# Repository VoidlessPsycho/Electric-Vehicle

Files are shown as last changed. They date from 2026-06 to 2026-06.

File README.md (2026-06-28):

# Voidless's Electric Vehicle

This project is an Electric Vehicle for the Science Olympiad Electric Vehicle event for the 2026-27 season. It uses N20 Motors, TB6612FNG Motor Driver, and ESP32 for movement.

**Demo Video:** https://youtu.be/8lS0Rzt4JzQ

Angle View Front
Angle View Back

[Journal](JOURNAL.md)

## How to Use
1. Turn on power by pressing button from battery pack.
2. Upload code from computer using USB-C and Arduino IDE.
3. Align toothpick and vehicle with start point on track, facing straight forward.
4. Use a pencil to press button in center of vehicle.

## How it Works
1. Pins are assigned to variables.
2. There is a configurable segments object to determine how far to go for each segment of the path. 
3. When the button is pressed, the motion part of the script activates. 
4. The vehicle uses encoder feedback and compares it to the calculated position of each motor to determine which segment the vehicle currently needs to be on, and uses PID loops and if statements to control the vehicle speed and direction.
5. The vehicle stops once it is detected that the vehicle has passed through all the segments. 

## Tech Stack
- Arduino IDE
- C++ (Programming)
- Onshape (CAD)
- Freeform/Excalidraw/Notebook (Brainstorming)
- Desmos Graphing Calculator (Path Planning)
- VS Code (Repository Management)
- Markdown (Journaling/Documentation)

AI Declaration: AI was used in programming the firmware for this device. 

## Images
CAD: \
Front
Side

[Wiring](https://app.cirkitdesigner.com/project/edc74d5a-a196-4ad5-98cb-bc518ee554fb): \
Circuit

Bill of Materials:
- 1 x Push Button
- 1 x 6xAA Battery Holder
- 6 x AA Batteries
- 1 x Ball Castor
- 2 x Banebots T40 1.625x5/8 in Wheels + Hubs
- 2 x 12V 1:30 Gearbox Polulu N20 Motors with Encoders
- 1 x ESP32 DevKit V1
- 1 x TB6612FNG Motor Driver
- 1 x 3D Printed Frame
- 1 x 3D Printed Motor Holder
- Dupont Wires (Female-Female)

## Motivation
I selected this event for Science Olympiad as I was interested in electronics. This event requires programming a microcontroller with C++ and learning motor control structures, like using PID control loops, trapezoidal motion profiles, and H-Bridge motor drivers. This project is meant to be a competitive device for the Electric Vehicle event, and I won 4th place with it at my Regional Tournament.

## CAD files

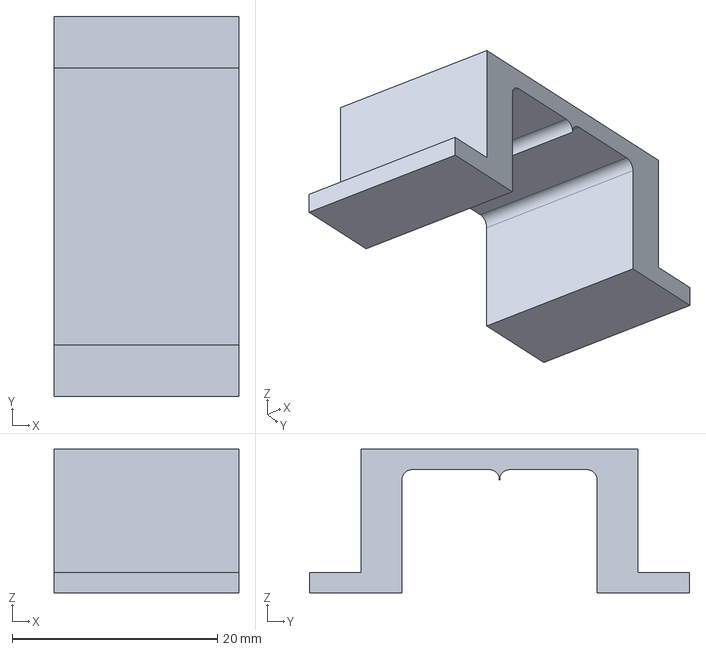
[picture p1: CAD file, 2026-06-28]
CAD/Motor Holder.step
18.0 x 37.0 x 14.0 mm

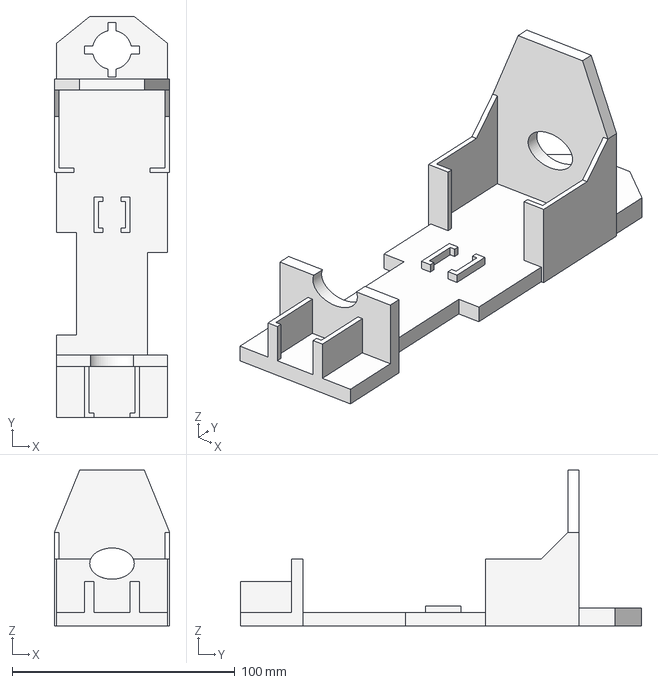
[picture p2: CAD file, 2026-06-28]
CAD/Frame.step
51.8 x 180.0 x 70.0 mm

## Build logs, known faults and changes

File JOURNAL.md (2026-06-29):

# Journal

**Total Number of Entries: 43** \
**Total Time Spent: 93.5 hours**

<hr>

### September 10, 2025: Analyzing Rules
I read through the guidelines for the Electric Vehicle event to figure out exactly what I had to do. The rules also included constraints on what I cannot do, such as limiting power to a maximum of 8 x AA Batteries for max of 12 V. \
The challenge requires the vehicle to go from the start point to the end point in a set amount of time. For bonus points, it can go through a gap made by cans to the left. This track is illustrated in the image below: \


**Time spent this session: 1 hour**
<hr>

### September 17: Finding Parts on Amazon
I knew I needed to make a robot car, with two motors, a microcontroller, and a motor driver. I decided to look for these components on Amazon. 

**Motors:** Because the Electric Vehicle had to be as thin as possible to get the most can bonus (cans closer together = more bonus points), I needed small motors so my chassis isn't too big. I found a type of motor called an N20 motor, which had a very small size. I found a lot of different options on both the Polulu (robotics parts company) website and Amazon. 
>   

**Microcontroller:** As I don't know too much about electronics yet, I wanted to go with a simple microcontroller that is beginner-friendly. I looked at the popular Arduino Uno R3, and its cheaper alternative, the Elegoo Uno R3. 
>  

**Motor Driver:** To control the motors using Pulse Width Modulation (PWM), a motor driver is necessary. I looked at the TB6612FNG module, which is an H-Bridge motor driver.
> 

Still need to decide which motors, microcontrollers, and motor drivers to buy specifically for my use case.

**Time spent this session: 2 hours**
<hr>

### October 8: Buying Basic Electronics
One thing I didn't discuss in the previous journal is what wheels I was gonna use. This is because I was thinking of using CDs as I have in other vehicle projects, albeit those were not electric. My "Scrambler" project I made previously looks similar to the below picture below, with CDs for wheels. 

 \
However, the CDs broke extremely easily, especially after using superglue to attach them to the axle. After remembering this, I decided to **NOT** use CDs for this project going forward.

The plan is to first buy basic parts like an Arduino, motors, etc., then figure out how to make the vehicle curve/follow and angular path and program it. 

**Steering Method:** First, I wanted to try the caliper steering method, and then the differential steering method if I am unable to implement caliper steering. Caliper steering requires more CADding, and differential steering requires more programming. 

**Parts Choices:** Below is an Amazon cart screenshot of different items I debated on purchasing: (Censored PII)

- **Motor**: I went back and reviewed my motor choices. N20 Motors can be used for both differential steering and caliper steering. I looked for some of these on Amazon, and I [found one](https://www.amazon.com/dp/B0F8NLB4CD/), but it didn't have any reviews, so I ended up not purchasing it. 
- **Microcontroller**: I chose to buy the [Elegoo Uno R3](https://www.amazon.com/ELEGOO-Starter-Tutorial-Compatible-Official/dp/B01DGD2GAO/)  because of it being cheaper than the Arduino Uno R3 for the same features, and also got a starter kit so that I could have other electronics to experiment with.
- **Motor Driver:** The [TB6612FNG](https://www.amazon.com/gp/product/B08J3S6G2N/) was more efficient than the L298n Motor Driver, but because I didnt have a [soldering iron](https://www.amazon.com/Soldering-Digital-Welding-Portable-Electric/dp/B08R3515SF/), I decided to go with the L298n instead.

I want to use a 3D-printed frame, a breadboard, and tape if necessary to construct my EV. 

Items I bought today:


**Time spent this session: 2.5 hours**
<hr>

### October 14: Experimenting with the Basic Kit
I got my Elegoo Starter Kit and started experimenting with it. If I need it, I'll get a Raspberry Pi Pico later. 

The battery pack had 12V and GND wires, but the ends were too big to fit into the breadboard power rails easily. This made it so the LED didn't light up.



I decided to use the power pins from the Elegoo Uno, and using a resistor made the LED light up properly and not burn out.



This is my first successful circuit!

**Time spent this session: 1.5 hours**
<hr>

### October 18: Motor Movement
I got the motor driver and motor, so I could finally start some moving parts. The L298n had screw terminals to attach the motors and other wires to. 

I made an Arduino program to make sure my motors worked. It spins the motor forward, spins it the other way, then stops. I also added interrupts to the encoders so I could track motor position on the serial encoder.

Motor Setup

Demo of Motor moving: https://youtu.be/Mmbqhapk2sQ

I also got a caliper for caliper steering and measurements, but I think its too cheap because it doesn't have two digits of decimal precision, only one, and it also is very bendy.

Caliper

**Time spent this session: 4 hours**
<hr>

### October 19: Steering Design Brainstorming
I made some sketches on how I could make the vehicle turn to go through the cans. I wanted to make the front axle be able to rotate horizontally, using either a screw or a hinge.
- **Screw:** The front axle would be able to rotate by being attached a screw, and this rotation would be tracked by a rotation sensor. Screw
- **Hinge:** The front axle would be attached on one side to a piece that would be attached by a hinge to the rest of the chassis, and the caliper on the other side of the front axle could be used to move it forward and back. As one end of the front axle is secured, the axle will be in an angled position. Hinge

I also researched different motor options, such as: 
- [Polulu](https://www.pololu.com/product/5213), which was too expensive at >$30.
- [Amazon N20](https://www.amazon.com/Lheng-Miniature-Geared-Encoder-265RPM/dp/B07RXCPSQR/), which was too low voltage and RPM (6V & 265 RPM, when I needed 12V & 600 RPM).
- [**12V DC Motor**](https://www.amazon.com/Motor-Encoder-Speed-Gearmotor-Robotics/dp/B07GNDG2NC/), which was my final choice as it would be a strong motor with quadrature encoders included. 

In addition, I researched absolute encoders to measure angle rotation of the front axle: [AS5600](https://www.adafruit.com/product/6357) and MT6701, and the MT6701 is better as it works at higher speeds.

At the moment, I don't want to use a pre-made kit and want to find the parts and design everything myself.

**Time spent this session: 3.5 hours**
<hr>

### November 6: Debating Buying a Kit
I've been thinking about making my own design, but it seems very challenging to CAD a working chassis for either differential or caliper steering design. 

I looked at the [Tektite Vehicle Kit](https://tektitebiz.com/product/electric-vehicle/ 
), but finally didn't end up buying it.

**Time spent this session: 0.5 hours**
<hr>

### November 7: Looking at caliper steering design
I looked at a caliper steering implementation that I found on a forum online, and it seemed very complicated for me to CAD and implement. 

Caliper

I couldn't fully understand it even after looking at it for a few minutes and trying to visualize how I could design it. 

**Time spent this session: 0.5 hours**
<hr>

### November 13: Chassis Manufacturing Problem
I thought about how I would actually manufacture my vehicle chassis today. The only 3d printers I have access to are the school's Dremel Digilab printers, which have max build length of like 6 inches. This is probably too small for my caliper frame, and I'd have to design it differently.

**Time spent this session: 0.5 hours**
<hr>

### November 17: Different Microcontroller Options
I re-evaluated different microcontroller options, this time looking at ESP32, RPI Pico 2, and STM32. While I found that they are basically the same, ESP32 also has wifi/bluetooth capability, which could be helpful for programming. 

I also realized I need a better caliper for caliper steering, as the method needs precision in order to function and turn the vehicle accurately. 

In addition, I looked at another caliper steering design, this time looking at the front axle mount. 

Front Axle Mount

With this, I would angle this mount based on the track length, with a lesser angle for longer track lengths. The vehicle would also start at an angle based on math and arcs. I would also use a scope to aim at the cans or endpoint. 

**Time spent this session: 2 hours**
<hr>

### November 18: Vehicle CAD with all current Materials
I decided to collect all the materials I had and make a CAD of my planned vehicle using Onshape. I also used 3d-printable parts from [TopFinishKits](https://topfinishkits.com/vehicle-electric-vehicle/) to make my CAD. However, this CAD can only go straight, so it needs to be changed in the future. 

All MaterialsCAD

**Time spent this session: 2 hours**
<hr>

### November 25: Purchasing Acurun Kit
While I had previously not wanted to buy the Acurun kit, after spending time trying to design a caliper steering kit, I realized I do not presently have the skills to achieve this. This is why I decided to buy the [Acurun EV](https://www.youtube.com/@AcuRunKits) kit off Etsy. \
The kit comes with a chassis STL file, two N20 Motors, a castor ball, a 6xAA battery pack, a SS1306 OLED display, a TB6612FNG motor driver with soldered headers, and wires. It does **NOT** come with wheels or the microcontroller. 

Acurun Kit

**Time spent this session: 2 hours**
<hr>

### November 27: Path Planning
I decided that caliper steering was too complicated, and I wasn't able to modify the previous journal's design to curve. \
The Acurun Kit uses differential steering, and I drew two possible paths for my vehicle in Freeform.



- **Blue:** Start the vehicle pointed diagonally towards the midpoint between the cans. The vehicle goes straight towards the cans, turns, and goes straight to the endpoint. 
- **Red:** Start the vehicle pointed straight towards the endpoint. The vehicle goes straight, then turns diagnoally to the left and continues. When the vehicle intersects with the vertical line going through the midpoint of the two cans, it turns to the right and goes straight through the cans. After, it turns to the right and goes diagonally until it reaches the vertical line formed by the first straight path. It then turns back to the left and continues straight until the endpoint. 

Planning this out now will help me program the differential drive later. 

**Time spent this session: 0.5 hours**
<hr>

### December 15: Kit Delivery
The Acurun EV kit was delivered and I began assembling it. However, I did not have a microcontroller or wheels or chassis, so I could not begin programming or testing. 

Kit Package

**Time spent this session: 1 hour**
<hr>

### December 20: Confirming ESP32 Usage Legality
Because the kit did not come with a microcontroller, I had to obtain my own. As discussed previously, the ESP32 would be a good option due to its wireless capabilities. I confirmed that I can use it according to the rules as long as I do not use the wireless capabilities during competition. 

**Time spent this session: 0.5 hours**
<hr>

### December 21: Getting an ESP32
I got an ESP32 from the Prototype Hackathon. Because my project used an ESP32 DevKit V1 Board, I was allowed to keep it, and I can use it for my vehicle project.

ESP32 Device

**Time spent this session: 1 hour**
<hr>

### January 14, 2026: Finalizing Microcontroller and Manufacturing Wheels
I decided to finalize my usage of the ESP32 Microcontroller. \
This is because if I went with the RPI Pico, I would need a 12v->5v buck convertor to ensure the battery doesn't burn out the RPI Pico (which can only accept 5v), and there is not enough space on my vehicle for that. \
In addition, I am using a 9v (6x1.5vAA) battery pack to make sure I don't burn out any of the hardware. \
I also made the decision to 3D print banebots wheels instead of buying them to save costs. 

Banebots Wheel CAD (1.625 in Diameter, 0.625 in Width):
Banebots Wheel CAD

**Time spent this session: 1 hour**
<hr>

### January 26: Sent files for print
I asked my Video Game Design/Engineering teacher at my high school to 3D print the frame and wheels on the 3D printer. He printed it on his home Bambu Lab X1C 3D printer. 

Frame CAD

(Banebots Wheel CAD in previous journal)

**Time spent this session: 0.5 hours**
<hr>

### January 28: Print Quality and Assembling Vehicle
My teacher gave me the completed 3D prints, and I assembled the vehicle. \
Because he didn't print the wheels with supports, the print quality was messed up and I had to use a box cutter knife to remove some of the stringing. \
I also had to cut away some of the plastic from the inside hole of the wheel, as it was not fitting on the wheel hubs on the motors. \
Wheel with Plastic Bits

I assembled the vehicle, connecting the wires to the different components using this wiring diagram, but modified to use an ESP32 DevKitV1 instead of an Arduino Nano 33 BLE:

Wiring Diagram: Wiring Diagram

Images of Assembled Vehicle: Side 1 Side 2

However, since the ESP32 is pretty big, it kept moving around as it wasn't secured and kept touching the wheels. 

To add grip to the wheels to make it actually move when on the ground, I am planning on using grip tape or rubber bands. 

**Time spent this session: 4 hours**
<hr>

### February 1: Setting Deadlines
I want the vehicle to be ready by 02/21 for the StanfordSO Invitational. This means I need to begin programming and get it competition-ready quickly.

**Time spent this session: 0.5 hours**
<hr>

### February 3: Choosing Path to Program
I want to use the BLUE turning method because it seems simpler to implement, with less turns to make it less complex to program. The RED turning method seemed simpler at first cause of aiming it straight forward but the turns are very hard to implement. 

I also might wanna switch to RPI Pico because the ESP32 is very big, and it's not fitting on the chassis properly.

**Time spent this session: 0.5 hours**
<hr>

### February 4: Programming with PID and Trapezoidal Motion Profile
I began writing code using the Arduino IDE and the help of Claude. 
- Program 1: I wrote a program that uses the N20 motors, encoders, display, and motor driver to make a simple path. It goes forward a set distance, turns 90 degrees, and drives forward again. This uses the quadrature encoder interrupts to count and figure out when to turn. 
- Program 2: To improve the straight-line accuracy and start and ending accuracy, I decided to use a closed-loop PID controller and a trapezoidal motion profile. This allows the vehicle to accelerate and decelerate at the beginning and end of each path, meaning it slips a lot less. When I press the button, it goes straight, turns 90 degrees twice, and ends accurately at an endpoint. 

**Time spent this session: 5 hours**
<hr>

### February 7: Fixing wiring problems
While uploading some new code, the hardware just refused to move. I realized this was for a few reasons:

1. The ground pins of the battery pack, ESP32, motors, and TB6612FNG motor driver were not all connected. Without this connection, the electricity won't flow where it needs to and the motors will not move.
2. The STBY (standby) pin of the TB6612FNG needs to be activated for the h-bridge motor driver to actually function. I pulled it up with 3.3v and it started working again.
3. I realized I wired my ESP32 incorrectly and used the bootup/strapping pins for GPIO. I rewired the ESP32 connecting everything to proper GPIOs and everything started working again. 

**Time spent this session: 3 hours**
<hr>

### February 9: Focusing on Motor Driver 
I investigated the TB6612FNG library and its included examples. I wanted to understand how the TB6612FNG motor driver worked, so I used the different programs to control the motors. 

The script moves each motor forward, backward, braking, and moves them together forward, backward, and braking. It also allows the robot to move in one direction like left/right, which is important for my vehicle to be able to follow the path. 

Because I know how the TB6612FNG works properly, I can start programming my vehicle more easily now. 

**Time spent this session: 2 hours**
<hr>

### February 10: H-Bridge Library problems
I tried using [this](https://github.com/pablopeza/TB6612FNG_ESP32/blob/master/examples/motors/motors.ino) TB6612FNG library for ESP32, but it didn't work. I think its because the pins weren't assigned properly, or the logic didnt work for my version of the ESP32.

Instead of trying to fix the library, I decided to start programming it like any other H-Bridge like l298n, and made a script that directly toggles the raw digital outputs (HIGH/LOW) for the direction pins (AIN1/AIN2 and BIN1/BIN2) and drives the speed using standard Arduino analogWrite() PWM signals.

I added to the script to drive the motors forward and backward and track encoder positions to the serial monitor, so I could ensure the motor driver and encoders were working together properly.

**Time spent this session: 3 hours**
<hr>

### February 11: Space Constraints Problem
Because the ESP32 doesn't fit on breadboard, it makes wiring really annoying. This is why I began to reconsider the Arduino Nano 33 BLE option, as it is really really small, like almost half the width of the ESP32. 

I still decided against using it because it is much more expensive than the ESP32, and I don't have enough time to get it and then program it. 

**Time spent this session: 0.5 hours**
<hr>

### February 12: Rubber Banded Wheels Failure
Vehicle Image

The vehicle has rubber bands on the 3D-printed wheels for grip. The ESP32 is being held up by the wires and their rigidity. 

A major problem was when I tried making it drive on the floor, and even when I just programmed it to go straight, the rubber bands caused horrible wobbles that led to it falling over. Even using PID didn't really help, as the wires still got caught. I need to probably switch to proper Banebots wheels and wire it properly.

**Time spent this session: 3 hours**
<hr>

### February 15: GND Pin Confusion
There are two GNDs on the TB6612FNG motor driver. I thought I had to connect both of them to the ESP32. However, there are only two GND pins, and one of them is already being used for a different component.

To fix this, I thought of soldering two wires coming out of the two GND pins on the motor driver together. I realized this was unnecessary, however, as only one GND pin needs to be connected to the ESP32. 

**Time spent this session: 2 hours**
<hr>

### February 16: SparkFun Library and Path Selection
I experimented [TB6612FNG SparkFun Library](https://github.com/sparkfun/SparkFun_TB6612FNG_Arduino_Library) to control the motors. The vehicle moved and went straight, without any implementation of encoders or a PID control loop. 

I modified the BLUE path and considered both options again:
Paths \
This time, the BLUE path turns before reaching the cans, and goes straight through it instead of turning at the cans. This is because there is not much space to turn in between the cans, especially when the cans are closer together for more bonus points. 

I decided to wait to program until my Banebots wheels arrive. 

**Time spent this session: 2 hours**
<hr>

### February 18: Wheels Delivery Delay
The wheels are arriving on 2/21, the day of the competition, so I won't have a vehicle ready for the competition :heavysob:.

**Time spent this session: 0.5 hours**
<hr>

### February 22: Wheels Delivery Delay x2
Our school did not permit us to attend the StanfordSO Invitational, so it ended up not mattering that I did not have the wheels on time.

Unfortunately, the wheels got delayed again by two days so I still can't program. 

**Time spent this session: 0.5 hours**
<hr>

### February 24: Wheels Arrived, Programming PID
I got the Banebots wheels and attached them to the motor hubs. It now moves but without encoders and PID.

I made a new program. It has two PID loops, one for each motor to make sure the PWM changes dynamically for each motor's errors. It also has interrupts for the encoders seperately on each motor to get input for the PID loops. 

I had to fix the wiring again with the STBY and VM pins causing problems. I also rewrote the PID to output raw PWM instead of velocity values. 

This spun the wheels properly and I can now program it smoothly.

**Time spent this session: 4 hours**
<hr>

### February 26: Made a Graph for Path Planning
I measured my EV and it came out to a width of 5.25 cm.

I made a graph on Desmos that dynamically updated the can location based on the length of the track.

Graph 

I hope to use this in conjunction with trigonometry and arcs to make path planning easier.

**Time spent this session: 1 hour**
<hr>

### March 2: IMU Consideration
I have decided on the RED path. 

To control turning, I can either use raw encoder output, or I could integrate an IMU with a gyroscope to measure what direction the robot is turning. 

IMU Options are BNO085, BNO055, and MPU6050. \
I looked at all of them, with their costs, and how to implement them, and decided that it would take too long for them to deliver, are too expensive, or would be too difficult to implement.

**Time spent this session: 2 hours**
<hr>

### March 7: ESP32 Burnout 
So I made a mistake today. 

When connecting the power wire from the battery pack to the ESP32, I mistakenly connected it to the 3.3v pin instead of the VIN pin. 

The only reason the ESP32 was able to work with 9v battery line is because of the LDO (Low-Dropout Regulator) that lowered the voltage coming in from the VIN pin. Since I mistakenly connected it to the 3.3v pin, the voltage wasn't reduced and the components on the board were fried. 

I felt extremely demotivated, especially considering the Regional Tournament, the final competition, was in one week on 3/14. 

I still decided to keep pushing, and purchased a pack of 3 ESP32 DevKit V1s from Amazon for like $10. 

I also then reviewed the voltage necessary for my motors. 

I had to make sure that I connected the VCC pin on the motors to the VCC on motor driver, and the motor driver was connected to the 9v. 

I am currently using 6V N20 motors, so it *can* run on 9v but will overheat. The 3.3v from the motor driver is a better power source. 

**Time spent this session: 3 hours**
<hr>

### March 8: More Material Options
I'm beginning to be able to fully understand how to program it now.

Messy Desk

I miscalculated the length of the track. I mistakenly thought the track was 10-20 meters, and the target time was 7-10 seconds. However, it was the reverse, with track length 7-10 meters, and target time 10-20 seconds. This meant I had to spend a lot of time reprogramming and setting new speeds for the motors. 

I then made the vehicle too fast, and it crashed into the wall repeatedly. 

I still haven't figured out how to turn the vehicle properly yet. 

The ESP32 in the EV gets warm, probably because 9V is a high voltage for just a LDO. The [Tektite RotEv Controller](https://tektitebiz.com/product/rotev-controller/) could solve this using a buck convertor, but would take too long to ship.   

To solve the warmth of ESP32, I thought about switching from Alkaline batteries to NiMH batteries, as 6xAlkaline = 9v while 6xNiMH = 7.2v. NiMH batteries are also rechargeable. I ended up not buying them because of time and money constraints. 

I also ran out of Claude prompts so I had to continue to manually program. 

Also, I looked at some example programs, that used a RAMSETE controller, but it needed multiple cores so it wasn't possible with just interrupts on ESP32.

**Time spent this session: 3.5 hours**
<hr>

### March 9: PID & Trapezoidal Motion Profile Implementation
My EV is beginning to work properly now. I implemented a PID loop and trapezoidal motion profile correction.

I used the example code below to understand how to implement a basic PI controller into my code. 

Example PI Code

I also analyzed the below diagram. It uses encoder output to find the measured speed and position of the motor, then compares it to the calculated speed and position. The error gets inputted into a PID controller, Proportional Integral Derivative, and then outputs a PWM as a percentage of motor voltage. 



Now I just have to test turns until the Vehicle follows the correct path, and then make some equations to determine how long to delay before starting movement for each distance to hit the target time.

I looked into a method of path following called Pure Pursuit, but it wouldn't work since I do not have an IMU. 

It took a while for me to implement the trapezoidal motion into PID and curves, but I was able to get it to work. 

I also made the last 50 cm of the path slower than the rest to ensure it doesn't skid past the end point. 

I used the Serial Plotter in the Arduino IDE to analyze the target RPM vs Measured RPM. 

Serial Plotter

To fix the oscillation, I needed to add a kV or Feed Forward value, which is a constant multiplied by velocity. I can also increase the I value in PID to smooth out the oscillations. 

**Time spent this session: 5 hours**
<hr>

### March 10: Motor Stalling Issues
When testing my vehicle, the motors started making crackling noises when I put it on the ground. They spun again when I lifted it.

After checking online, I realized this is because the motors were stalling from not having enough power. This is because the batteries were running out of power very quickly from the high power draw the motors had.

I had to replace batteries frequently (every 3-5 runs) to ensure accuracy and prevent stalling.

**Time spent this session: 2 hours**
<hr>

### March 11: Trapezoidal Motion Profiles
I looked at some more graphs and example code to understand how to implement trapezoidal motion profiles to reduce skid for my vehicle at the end of each segment. 

The graph below shows how I can program the robot to accelerate and decelerate at the beginning and end. This is to ensure that the vehicle travels precisely. Without the acceleration and deceleration periods, the motor would not accurately shift speeds and the vehicle wouldn't end up in the correct place.

Trapezoidal Motion Graph

The below code is an example implementation of the above graph. 

Graph Implementation Code

After implementing code similar to the above to have a trapezoidal shape graph in my code, I got the below results in the Serial Plotter, which were pretty good for my vehicle use case:

Serial Plotter

**Time spent this session: 3 hours**
<hr>

### March 12: Tweaking the Program
With the March 14 deadline coming up, I realized I wouldn't be able to get it perfect without another week to work on it. So I just hoped to make it good enough to use in competition. 

I got it to go in circles like a race car, which is not very helpful, but at least its moving in one direction. 

My straight line segments of the path were still inconsistent, so I had to continue to tune PID and trapezoidal motion.

I also checked the rules and rules clarifications to ensure that I can tape my battery pack to the EV after impounding it. This is because batteries need to be impounded separately, and I need to be able to attach the batteries again after impounding it. Also, the only way to attach the battery pack to my ev is by taping it.

**Time spent this session: 4 hours**
<hr>

### March 13: The Final Work Day
As the competition is tomorrow, today is the last day to work on the EV. I ended up staying up until 3AM to work on the EV, with competition at 7AM :sob:. I wish I had someone to work with me this late. 

List of Problems I Worked Through Today/Tonight:
- **Pausing between each segment**: Due to implementing trapezoidal motion, the vehicle stopped after each straight/turn section. This added a lot of time meaning I wasn't able to reach the target time. I had to remove the trapezoidal motion in between to make the delta calculations for acceleration and deceleration not mess up. This allowed me to keep most of the code but just remove some parts.
- **Battery problems**: The 6xAA 1.5V Alkaline Duracell batteries ran out of power very frequently with the power draw from the motors. When the voltage dropped, the PID immediately began to fail because it was dependent on constant, full voltage from the batteries. It couldn't reach the RPM necessary and the distances werent consistent or fast enough. I had to buy batteries from Target at like 10pm and it cost another $20. I should have used NiMH rechargeables earlier, but oh well. 
- **Simplifying Path**: Because of the inconsistencies with PID, I decided to make it easier by sacrificing more points from my can bonus. I decided to go with a can width of 25 cm instead of a smaller width of 10 cm. This would save me a lot of headache and make it less risky during competition.
- **Disregarding Time Bonus**: While you get more points for being closer to the target time which is between 7-10 cm, I realized that my vehicle is too slow for this, going around 14-20 seconds instead. This is okay though, as the time bonus score is negligible compared to the distance and can bonus scores. 

**Final Run**: I ended up getting 2 cm away from end point, 14 seconds time, with a 7 cm distance and 50 cm can bonus. I think this is what I'm going to run tomorrow for competition day. 

**Time spent this session: 8 hours**
<hr>

### March 14: Competition Day
The robot went fairly well. I got 4th place overall.

Target Time: 15s \
Target Distance: 9m \
Distance Score: 84cm away from end point \
Time Score: 17.88s \
Can Bonus: None (went to the left of both cans) 

Demo @ Home: https://youtube.com/shorts/tnM1iEZ0sQo \
**Demo @ Competition**: https://youtu.be/8lS0Rzt4JzQ

**Time spent this session: 1 hour**
<hr>

### June 27: README
Today, I CADded the robot in Onshape to make it presentable for the README. I imported a lot of parts from Onshape. I recorded it using Lookout.

Angle view
Side view

I also made a wiring diagram using Cirkit Designer. \
https://app.cirkitdesigner.com/project/edc74d5a-a196-4ad5-98cb-bc518ee554fb
Circuit

And I wrote the README.md.

**Time spent this session: 4 hours**
<hr>

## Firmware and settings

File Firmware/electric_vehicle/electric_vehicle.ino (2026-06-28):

// ============================================================
//  Science Olympiad Electric Vehicle Controller
//  Hardware : ESP32 DevKit V1, TB6612FNG, 2x N20 1:30 6V
//             360 PPR encoders (after gearbox), 9V battery
// ============================================================

// ─── Pin Definitions ────────────────────────────────────────
#define AIN1 32
#define AIN2 33
#define PWMA 25
#define BIN1 26
#define BIN2 27
#define PWMB 14
#define STBY 13

#define LEFT_ENC_A  19
#define LEFT_ENC_B  18
#define RIGHT_ENC_A 17
#define RIGHT_ENC_B 16

#define StartButton 4

// ─── LEDC (PWM) channels ────────────────────────────────────
#define LEDC_A    0
#define LEDC_B    1
#define LEDC_FREQ 20000
#define LEDC_RES  8       // 8-bit → 0–255

// ─── Physical Constants ─────────────────────────────────────
#define ENCODER_PPR      179.16f   // pulses per rev after gearbox
#define WHEEL_DIAM_MM     41.275f   // *** measure your wheel ***
#define WHEEL_BASE_MM    44.3f   // *** centre-to-centre ***

#define MM_PER_REV        (PI * WHEEL_DIAM_MM)
#define COUNTS_PER_MM     (ENCODER_PPR / MM_PER_REV)

// ─── Gains  (tune in order: KFF → KSP → KDP → KSI → KDI → KST) ────────
//
//  KFF : feedforward scale on speedProfile
//        Start ~1.0, adjust until motor roughly tracks open-loop
//  KSP : proportional on S_Error (speed error)
//  KDP : proportional on D_Error (distance error)
//  KSI : integral on S_Error — eliminates steady-state speed offset
//        Start ~0.0, increase slowly; too large causes oscillation
//  KDI : integral on D_Error — eliminates steady-state distance offset
//        Start ~0.0, increase slowly; too large causes overshoot
//  KST : proportional on steering error (straight segments only)
//
float KFF = 0.5f;   // was 0.7
float KSP = 0.8f;   // was 0.5 — more speed correction
float KDP = 1.2f;   // was 0.8 — more distance correction
float KST = 2.1f;

// ─── Integral windup limit (counts/s equivalent) ────────────
// Prevents integral from growing unbounded during long errors.
// Set to ~20–30% of MAX_SPEED as a starting point.
#define INTEGRAL_LIMIT 80.0f   // tighter — prevents windup fighting battery sag
float KSI = 0.02f;  // back off integral — it's making things worse on weak batteries
float KDI = 0.05f;

// ─── Motion Profile Parameters ──────────────────────────────
float ACCEL_RATE = 1500.0f;    // counts/s²
float DECEL_RATE = 1500.0f;    // counts/s²
float MAX_SPEED  = 1500.0f;   // counts/s — set to measured free-run speed

// ─── Sequence ───────────────────────────────────────────────
// curveDelta = extra counts outer wheel travels vs inner
//   > 0 → right turn,  < 0 → left turn
struct Segment {
  float distanceMM;
  float curveDelta;
  bool  isCurve;
};

// ─── Start Delay ─────────────────────────────────────────────
float START_DELAY_MS = 0.0f;  // *** change this to your desired delay ***
const float trackLen = 0.0f;
const float startEndDist = ((trackLen - 7.0)/2)*1000.0;

// *** EDIT THIS to match your course ***
const Segment SEQUENCE[] = {
  {startEndDist, 0.0, false},
  {1800.0, 0.0, false},
  {800.0, -480.0, true},
  {1200.0, 550.0, true},
  {1350.0, 0.0, false},
  {850.0, 500.0, true},
  {1100.0, -200.0, true},
  {2800.0, 0.0, false},
  {startEndDist, 0.0, false}
};
const int NUM_SEGMENTS = sizeof(SEQUENCE) / sizeof(SEQUENCE[0]);

// ─── Encoder Counts (ISR-updated) ───────────────────────────
volatile long leftCount  = 0;
volatile long rightCount = 0;

// ─── Per-segment state ──────────────────────────────────────
int   segIndex       = 0;
long  segStartLeft   = 0;
long  segStartRight  = 0;
long  segStartTime_us = 0;

// Trapezoidal profile timing (absolute microseconds from segment start)
long  timeEndAccel_us = 0;
long  timeEndConst_us = 0;
long  timeEndDecel_us = 0;

float segMaxSpeed       = 0.0f;
float segTargetCounts   = 0.0f;
float leftTargetCounts  = 0.0f;
float rightTargetCounts = 0.0f;

bool  running = false;

// ─── Integral accumulators (reset each segment) ─────────────
float leftIntegral  = 0.0f;   // ← NEW
float rightIntegral = 0.0f;   // ← NEW

// ─── Control loop timing ────────────────────────────────────
long  prevTime_us    = 0;
long  prevLeftCount  = 0;
long  prevRightCount = 0;

// ═══════════════════════════════════════════════════════════
//  ENCODER ISRs
// ═══════════════════════════════════════════════════════════
void IRAM_ATTR leftEncA_ISR() {
  if (digitalRead(LEFT_ENC_A) == digitalRead(LEFT_ENC_B)) leftCount++;
  else leftCount--;
}
void IRAM_ATTR rightEncA_ISR() {
  if (digitalRead(RIGHT_ENC_A) == digitalRead(RIGHT_ENC_B)) rightCount++;
  else rightCount--;
}

// ═══════════════════════════════════════════════════════════
//  MOTOR DRIVER
// ═══════════════════════════════════════════════════════════
void setMotorA(int pwm) {
  pwm = constrain(pwm, -255, 255);
  if (pwm >= 0) { digitalWrite(AIN1, HIGH); digitalWrite(AIN2, LOW);  }
  else          { digitalWrite(AIN1, LOW);  digitalWrite(AIN2, HIGH); pwm = -pwm; }
  ledcWrite(PWMA, pwm);
}
void setMotorB(int pwm) {
  pwm = constrain(pwm, -255, 255);
  if (pwm >= 0) { digitalWrite(BIN1, HIGH); digitalWrite(BIN2, LOW);  }
  else          { digitalWrite(BIN1, LOW);  digitalWrite(BIN2, HIGH); pwm = -pwm; }
  ledcWrite(PWMB, pwm);
}
void stopMotors() {
  digitalWrite(AIN1, LOW); digitalWrite(AIN2, LOW); ledcWrite(PWMA, 0);
  digitalWrite(BIN1, LOW); digitalWrite(BIN2, LOW); ledcWrite(PWMB, 0);
}

// ═══════════════════════════════════════════════════════════
//  TRAPEZOIDAL PROFILE
//
//  speedProfile(t)  →  S_Profile  [counts/s]
//  distProfile(t)   →  D_Profile  [counts]   via d = v0*t + 0.5*a*t²
//
//  Both are functions of elapsed microseconds since segment start.
// ═══════════════════════════════════════════════════════════
float speedProfile(long t_us) {
  float t  = t_us * 1e-6f;
  float tA =  timeEndAccel_us                         * 1e-6f;
  float tC = (timeEndConst_us - timeEndAccel_us)      * 1e-6f;
  float tD = (timeEndDecel_us - timeEndConst_us)      * 1e-6f;

  if (t <= 0.0f)           return 0.0f;
  if (t <= tA)             return ACCEL_RATE * t;
  if (t <= tA + tC)        return segMaxSpeed;
  if (t <= tA + tC + tD)   return segMaxSpeed - DECEL_RATE * (t - tA - tC);
  return 0.0f;
}

float distProfile(long t_us) {
  float t  = t_us * 1e-6f;
  float tA =  timeEndAccel_us                         * 1e-6f;
  float tC = (timeEndConst_us - timeEndAccel_us)      * 1e-6f;
  float tD = (timeEndDecel_us - timeEndConst_us)      * 1e-6f;

  float dA = 0.5f * ACCEL_RATE * tA * tA;
  float dC = segMaxSpeed * tC;

  if (t <= 0.0f)           return 0.0f;
  if (t <= tA)             return 0.5f * ACCEL_RATE * t * t;
  if (t <= tA + tC)        return dA + segMaxSpeed * (t - tA);
  if (t <= tA + tC + tD) {
    float td = t - tA - tC;
    return dA + dC + segMaxSpeed * td - 0.5f * DECEL_RATE * td * td;
  }
  return dA + dC + (segMaxSpeed * tD - 0.5f * DECEL_RATE * tD * tD);
}

// ═══════════════════════════════════════════════════════════
//  SEGMENT SETUP
// ═══════════════════════════════════════════════════════════
void startSegment(int idx) {
  const Segment &s = SEQUENCE[idx];

  segStartLeft    = leftCount;
  segStartRight   = rightCount;
  segStartTime_us = micros();

  // Reset integral accumulators on each new segment               ← NEW
  leftIntegral  = 0.0f;                                           // ← NEW
  rightIntegral = 0.0f;                                           // ← NEW

  // Per-wheel target counts
  float avgCounts = s.distanceMM * COUNTS_PER_MM;
  leftTargetCounts  = avgCounts + (s.isCurve ?  s.curveDelta * 0.5f : 0.0f);
  rightTargetCounts = avgCounts + (s.isCurve ? -s.curveDelta * 0.5f : 0.0f);
  segTargetCounts   = avgCounts;

  // Peak speed capped for short moves
  segMaxSpeed = min(MAX_SPEED, sqrtf(ACCEL_RATE * segTargetCounts));

  float tA = segMaxSpeed / ACCEL_RATE;
  float tD = segMaxSpeed / DECEL_RATE;
  float dA = 0.5f * ACCEL_RATE * tA * tA;
  float dD = segMaxSpeed * tD - 0.5f * DECEL_RATE * tD * tD;
  float distConst = segTargetCounts - dA - dD;

  if (distConst < 0.0f) {
    // Triangular profile — no constant-speed phase
    segMaxSpeed = sqrtf(segTargetCounts * ACCEL_RATE * DECEL_RATE
                        / (ACCEL_RATE + DECEL_RATE));
    tA = segMaxSpeed / ACCEL_RATE;
    tD = segMaxSpeed / DECEL_RATE;
    distConst = 0.0f;
  }

  float tC = (segMaxSpeed > 0.0f) ? distConst / segMaxSpeed : 0.0f;

  timeEndAccel_us = (long)(tA * 1e6f);
  timeEndConst_us = timeEndAccel_us + (long)(tC * 1e6f);
  timeEndDecel_us = timeEndConst_us + (long)(tD * 1e6f);
}

// ═══════════════════════════════════════════════════════════
//  CONTROL LOOP — called every ~5 ms
//
//  Diagram implementation (now with integral term):
//
//    S_Error = speedProfile(t) − speedActual       [counts/s]
//    D_Error = distProfile(t)  − distActual        [counts]
//
//    P   = KSP * S_Error  +  KDP * D_Error
//    I   = I_Last + KSI * S_Error + KDI * D_Error  ← NEW
//    FF  = KFF * speedProfile(t)
//    PWM = P + I + FF
// ═══════════════════════════════════════════════════════════
void controlLoop() {
  if (!running) return;

  long now_us = micros();
  float dt = (now_us - prevTime_us) * 1e-6f;
  if (dt < 0.001f) return;

  // ── 1. Snapshot encoders ────────────────────────────────
  long lc = leftCount;
  long rc = rightCount;

  // ── 2. Actual speed  [counts/s] ─────────────────────────
  // Replace the two speed lines with a low-pass filter
  static float leftSpeedFilt  = 0.0f;
  static float rightSpeedFilt = 0.0f;
  float alpha = 0.4f;  // 0=frozen, 1=raw — tune between 0.3–0.6
  leftSpeedFilt  = alpha * ((lc - prevLeftCount) / dt) + (1.0f - alpha) * leftSpeedFilt;
  rightSpeedFilt = alpha * ((rc - prevRightCount) / dt) + (1.0f - alpha) * rightSpeedFilt;
  float leftSpeedActual  = leftSpeedFilt;
  float rightSpeedActual = rightSpeedFilt;
  prevLeftCount  = lc;
  prevRightCount = rc;
  prevTime_us    = now_us;

  // ── 3. Elapsed time in segment ──────────────────────────
  long t_us = now_us - segStartTime_us;

  // ── 4. Profile values for average wheel ─────────────────
  float sProfile = speedProfile(t_us);   // S_Profile [counts/s]
  float dProfile = distProfile(t_us);    // D_Profile [counts]

  // ── 5. Scale profiles to each wheel (curve support) ─────
  float leftSProfile  = sProfile;
  float rightSProfile = sProfile;
  float leftDProfile  = dProfile;
  float rightDProfile = dProfile;

  if (SEQUENCE[segIndex].isCurve && segTargetCounts > 0.0f) {
    float lRatio = leftTargetCounts  / segTargetCounts;
    float rRatio = rightTargetCounts / segTargetCounts;
    leftSProfile  = sProfile * lRatio;
    rightSProfile = sProfile * rRatio;
    leftDProfile  = dProfile * lRatio;
    rightDProfile = dProfile * rRatio;
  }

  // ── 6. Actual distance this segment [counts] ────────────
  float leftDistActual  = (float)(lc - segStartLeft);
  float rightDistActual = (float)(rc - segStartRight);

  // ── 7. S_Error and D_Error (diagram signal names) ───────
  float leftSError  = leftSProfile  - leftSpeedActual;
  float rightSError = rightSProfile - rightSpeedActual;

  float leftDError  = leftDProfile  - leftDistActual;
  float rightDError = rightDProfile - rightDistActual;

  // ── 8. P = KSP * S_Error  +  KDP * D_Error ─────────────
  float leftP  = KSP * leftSError  + KDP * leftDError;
  float rightP = KSP * rightSError + KDP * rightDError;

  // ── 9. I = I_Last + KSI * S_Error + KDI * D_Error ──────  ← NEW
  //         (anti-windup: clamp accumulator to ±INTEGRAL_LIMIT)
  leftIntegral  = constrain(leftIntegral  + KSI * leftSError  + KDI * leftDError,
                            -INTEGRAL_LIMIT, INTEGRAL_LIMIT);
  rightIntegral = constrain(rightIntegral + KSI * rightSError + KDI * rightDError,
                            -INTEGRAL_LIMIT, INTEGRAL_LIMIT);

  // ── 10. FF = KFF * speedProfile ─────────────────────────
  float leftFF  = KFF * leftSProfile;
  float rightFF = KFF * rightSProfile;

  // ── 11. PWM = P + I + FF ────────────────────────────────  ← NEW (added I)
  float leftOut  = leftP  + leftIntegral  + leftFF;
  float rightOut = rightP + rightIntegral + rightFF;

  // ── 12. Steering correction (straight segments only) ────
  if (!SEQUENCE[segIndex].isCurve) {
    float steerError = leftDistActual - rightDistActual;
    leftOut  -= KST * steerError;
    rightOut += KST * steerError;
  }

  // ── 13. Drive motors ────────────────────────────────────
  float pwmScale = 255.0f / MAX_SPEED;
  setMotorA((int)(leftOut  * pwmScale));
  setMotorB((int)(rightOut * pwmScale));

  // ── 14. Serial Plotter output ───────────────────────────
  // Plot 1: Speed tracking
  Serial.printf("sPro:%.1f lSpd:%.1f rSpd:%.1f lSErr:%.1f rSErr:%.1f dPro:%.1f lDst:%.1f rDst:%.1f lDErr:%.1f rDErr:%.1f lInt:%.1f rInt:%.1f lP:%.1f rP:%.1f\n",
    sProfile, leftSpeedActual, rightSpeedActual, leftSError, rightSError, dProfile, leftDistActual, rightDistActual, leftDError, rightDError, leftIntegral, rightIntegral, leftP, rightP);

  // Plot 2: Distance tracking (comment Plot 1, uncomment this)
  // Serial.printf("dPro:%.1f lDst:%.1f rDst:%.1f lDErr:%.1f rDErr:%.1f\n",
  //   dProfile, leftDistActual, rightDistActual, leftDError, rightDError);

  // Plot 3: Integral terms (comment others, uncomment this)   ← NEW
  // Serial.printf("lInt:%.1f rInt:%.1f lP:%.1f rP:%.1f\n",
  //   leftIntegral, rightIntegral, leftP, rightP);

  // ── 15. Segment complete check ───────────────────────────
  float avgDistActual = (leftDistActual + rightDistActual) * 0.5f;
  bool  timeUp   = (t_us > timeEndDecel_us + 150000L);
  bool distDone = (avgDistActual >= segTargetCounts * 0.99f)
             && (t_us >= timeEndDecel_us);

  if (timeUp || distDone) {
    segIndex++;
    if (segIndex >= NUM_SEGMENTS) {
      stopMotors();
      running = false;
      Serial.println("=== SEQUENCE COMPLETE ===");
    } else {
      startSegment(segIndex);
    }
  }
}

// ═══════════════════════════════════════════════════════════
//  SETUP
// ═══════════════════════════════════════════════════════════
void setup() {
  Serial.begin(115200);

  pinMode(AIN1, OUTPUT); pinMode(AIN2, OUTPUT);
  pinMode(BIN1, OUTPUT); pinMode(BIN2, OUTPUT);
  pinMode(STBY, OUTPUT); digitalWrite(STBY, HIGH);

  ledcAttach(PWMA, LEDC_FREQ, LEDC_RES);
  ledcAttach(PWMB, LEDC_FREQ, LEDC_RES);
  stopMotors();

  pinMode(LEFT_ENC_A,  INPUT_PULLUP); pinMode(LEFT_ENC_B,  INPUT_PULLUP);
  pinMode(RIGHT_ENC_A, INPUT_PULLUP); pinMode(RIGHT_ENC_B, INPUT_PULLUP);
  attachInterrupt(digitalPinToInterrupt(LEFT_ENC_A),  leftEncA_ISR,  CHANGE);
  attachInterrupt(digitalPinToInterrupt(RIGHT_ENC_A), rightEncA_ISR, CHANGE);

  pinMode(StartButton, INPUT_PULLUP);
  Serial.println("Ready — press button to start.");
}

// ═══════════════════════════════════════════════════════════
//  LOOP
// ═══════════════════════════════════════════════════════════
static bool lastBtn = HIGH;

void loop() {
  bool btn = digitalRead(StartButton);

  if (lastBtn == HIGH && btn == LOW && !running) {
    delay(20);
    delay((int)START_DELAY_MS);  // ← add this line
    leftCount = 0; rightCount = 0;
    segIndex  = 0;
    prevLeftCount = 0; prevRightCount = 0;
    prevTime_us   = micros();
    running = true;
    startSegment(0);
    Serial.println("=== SEQUENCE START ===");
  }
  lastBtn = btn;

  controlLoop();
  delay(5);
}
